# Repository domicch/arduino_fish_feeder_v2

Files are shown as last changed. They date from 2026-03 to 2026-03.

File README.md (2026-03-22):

# Arduino Fish Feeder v2

An automatic fish feeder designed for small, precise dosages. Built around an Arduino Nano with a stepper motor driving a 14-well rotating dispenser and a servo motor to tap food through.

## Photos

<p float="left">
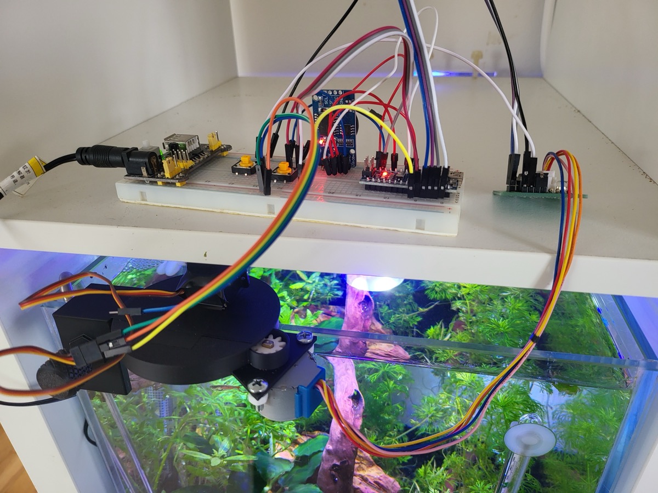
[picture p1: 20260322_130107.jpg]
  
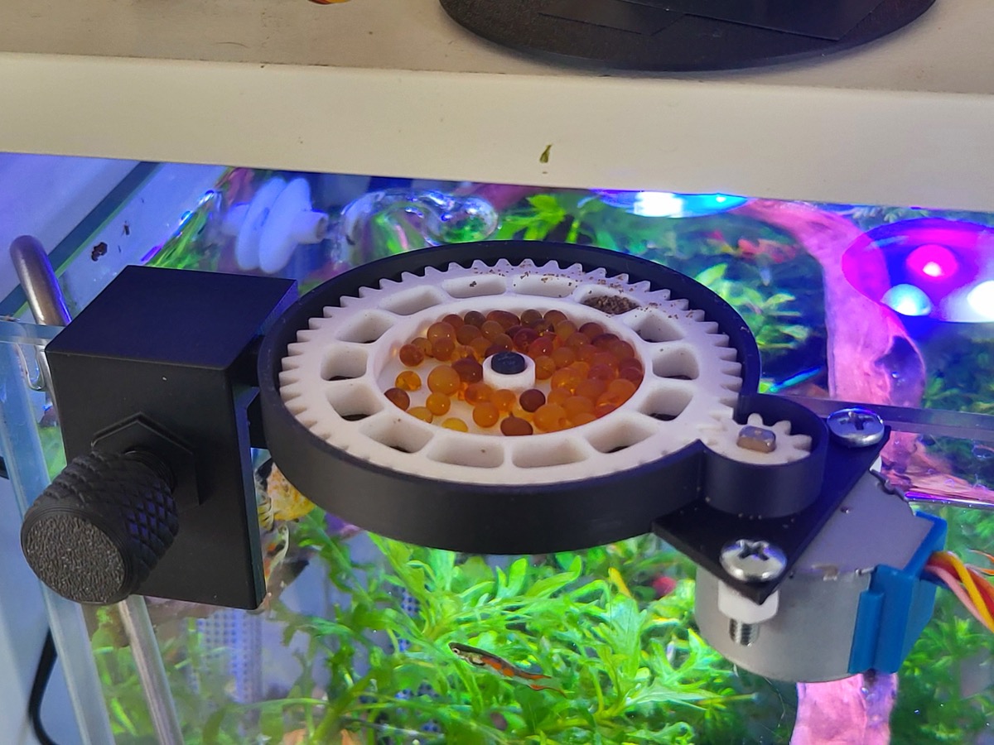
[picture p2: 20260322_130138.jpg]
  
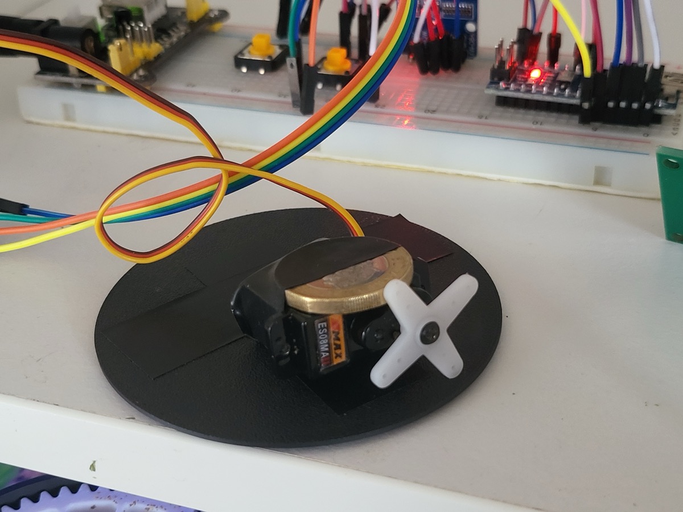
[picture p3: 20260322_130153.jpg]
  
</p>

## 3D Model

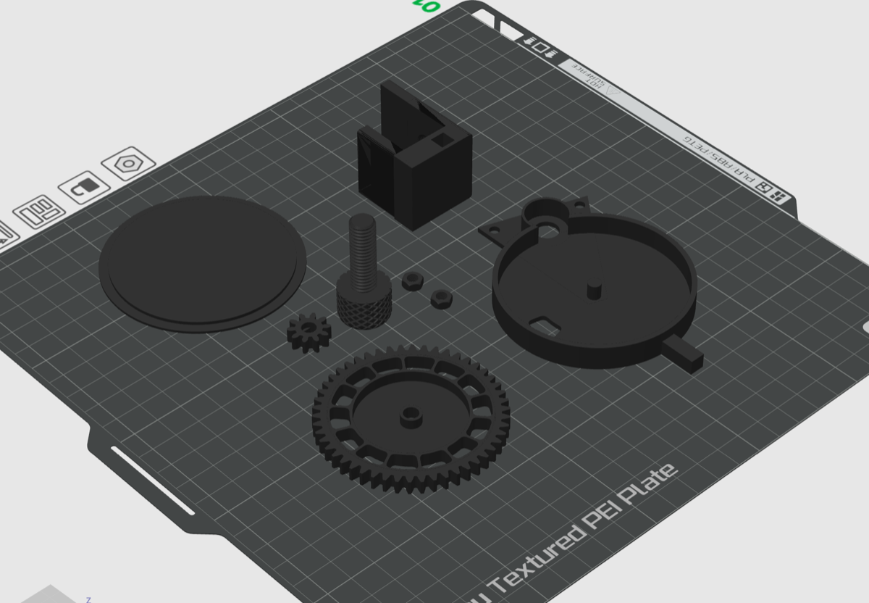
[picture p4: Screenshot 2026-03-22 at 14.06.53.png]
3mf screenshot


The enclosure and dispenser wheel are designed in Bambu Lab's 3MF format. The model file is `models.3mf`.

## Purpose

Most commercial fish feeders dispense food in large, imprecise quantities and only support basic daily scheduling. This feeder is designed for:

- **Precise, small dosages** — a 14-well rotating dispenser controls exactly how much food is released per feeding
- **Flexible scheduling** — feedings can be configured to specific dates and times, not just a daily interval

## Hardware

| Component | Purpose |
|---|---|
| Arduino Nano | Microcontroller |
| 28BYJ-48 stepper motor + ULN2003 driver board | Rotates the food dispenser wheel |
| Servo motor | Taps the dispenser to ensure food drops through |
| DS3231 RTC module (AT24C32 IIC) | Keeps accurate time for scheduling |
| 12V DC transformer + 12V to 5V converter board | Powers the system |
| 3D printed parts | Enclosure, gear system, and dispenser wheel |

### Wiring

| Pin | Connection |
|-----|---|
| D6 | Servo signal |
| D7 | Test button (active low, internal pull-up) |
| D8–D11 | ULN2003 stepper driver |
| A4 | RTC SDA |
| A5 | RTC SCL |

## Technical Challenges Solved

### Low stepper motor torque
The 28BYJ-48 produces very little torque on its own. A **gear reduction system** (3D printed) multiplies the torque enough to reliably rotate the food dispenser.

### Food sticking in wells
Food particles can stick inside the wells and fail to fall through. A **servo motor taps the dispenser** for 60 seconds after each rotation, shaking food loose.

### Precise portioning
The dispenser wheel has **14 wells**. Each feeding advances the wheel by exactly 1/14th of a revolution (730 steps of the stepper motor), releasing one pre-measured portion. The wheel also includes a dedicated space for a **moisture desiccant** to keep the food dry and prevent clumping.

## Software

### Libraries required

- `Stepper.h` (Arduino built-in)
- `Servo.h` (Arduino built-in)
- `RTClib` by Adafruit

### How to compile and flash

1. Install [Arduino IDE](https://www.arduino.cc/en/software)
2. Install the **RTClib** library via the Arduino Library Manager (`Sketch > Include Library > Manage Libraries`, search for `RTClib` by Adafruit)
3. Open `arduino_fish_feeder_v2.ino` in Arduino IDE
4. Select **Arduino Nano** as the board and the correct COM/serial port
5. Click **Upload**

### Configuring the schedule

Feeding times are hard-coded in the `schedules` array near the top of the `Scheduler` class:

```cpp
int schedules[20][6] = { // [year, month, day, hour, minute, second]
    {2026, 3, 22, 0, 10, 0},
    // add more entries here
};
```

Up to 20 entries are supported. The firmware automatically selects the next upcoming scheduled time.

### Setting the RTC clock

With the device connected via USB, open the Arduino IDE Serial Monitor (9600 baud) and send:

- `u` — enter interactive prompts to set the current date and time
- `t` — print the current time read from the RTC

### Manual test feeding

Press the button on **D7** to trigger an immediate feeding cycle (debounced to 500 ms).

## Future Improvements

- More flexible scheduling (recurring daily/weekly rules rather than specific timestamps)
- Wireless control — adjust schedule and trigger feeding remotely over Wi-Fi or Bluetooth

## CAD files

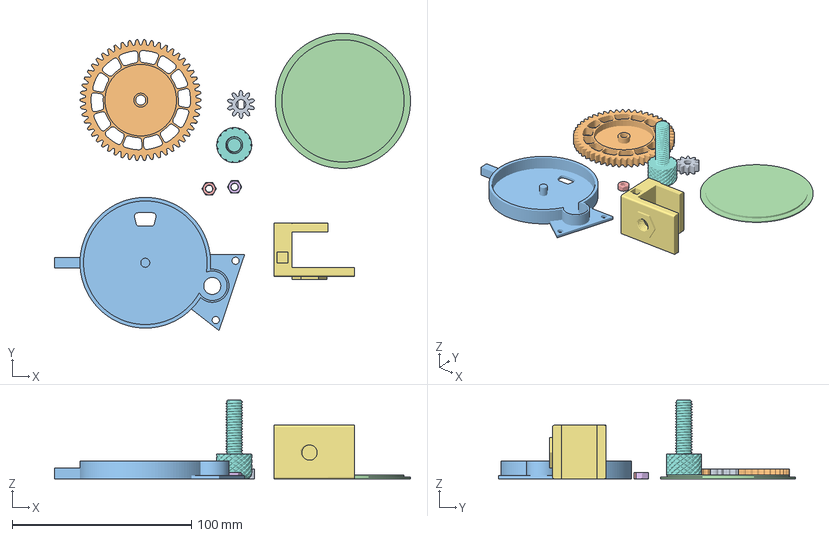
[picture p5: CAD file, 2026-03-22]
models.3mf
198.8 x 166.1 x 44.0 mm
small-gear.stl
big-gear.stl
container.stl
lid.stl
M4 Nut.stl.stl x 2
mount.stl
滚花螺丝.stl

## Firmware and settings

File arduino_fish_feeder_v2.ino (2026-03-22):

#include <Stepper.h>

#include <RTClib.h>
#include <Servo.h>


/**
 * Connections:
 *
 * D6 - servo control pin
 * D7 - test button
 * A4 - CLK SDA
 * A5 - CLK SCL
*/

class Scheduler {
    private:
        RTC_DS3231 rtc;

        int schedules[20][6] = { // [year, month, day, hour, minute, second]
            {2026, 3, 22, 0, 10, 0},            
        };

        bool isAlarmSet = false;
        DateTime nextAlarm;
        void setAlarm();
        String printDateTime(DateTime datetime);
        String printTime(DateTime datetime);

    public:
        void init();
        void setTime();
        String printNow();
        String printAlarm();
        bool checkAlarm();
        void clearAlarm();
        DateTime now();
};

void Scheduler::init() {
    rtc.begin();
    rtc.disable32K();
}

void Scheduler::setTime() {
    // ask user to enter new date and time
    const char txt[6][15] = { "year [4-digit]", "month [1~12]", "day [1~31]",
                            "hours [0~23]", "minutes [0~59]", "seconds [0~59]"};
    String str = "";
    long newDate[6];

    while (Serial.available()) {
    Serial.read();  // clear serial buffer
    }

    for (int i = 0; i < 6; i++) {

      Serial.print("Enter ");
      Serial.print(txt[i]);
      Serial.print(": ");

      while (!Serial.available()) {
          ; // wait for user input
      }

      str = Serial.readString();  // read user input
      newDate[i] = str.toInt();   // convert user input to number and save to array

      Serial.println(newDate[i]); // show user input
    }

    // update RTC
    rtc.adjust(DateTime(newDate[0], newDate[1], newDate[2], newDate[3], newDate[4], newDate[5]));
    Serial.println("RTC Updated!");
}

String Scheduler::printDateTime(DateTime datetime)
{
    char value[30];

    int ss = datetime.second();
    int mm = datetime.minute();
    int hh = datetime.hour();
    int DD = datetime.dayOfTheWeek();
    int dd = datetime.day();
    int MM = datetime.month();
    int yyyy = datetime.year();

    sprintf(value, "%02d-%02d-%04d %02d:%02d:%02d",
            dd, MM, yyyy, hh, mm, ss);
    
    return String(value);
}

String Scheduler::printTime(DateTime datetime)
{
    char value[6];

    int year = datetime.year();
    int month = datetime.month();
    int day = datetime.day();
    int mm = datetime.minute();
    int hh = datetime.hour();

    sprintf(value, "%02d/%02d/%02d %02d:%02d",
            year, month, day, hh, mm);
    
    return String(value);
}

void Scheduler::setAlarm() {
    DateTime now = rtc.now();
    int closestFutureIndex = -1;

    if(sizeof(schedules) == 0) {
        return;
    }

    int rows = sizeof(schedules) / sizeof(schedules[0]);

    // find the closest future timestamp
    for(int i = 0; i < rows; i++) {
        DateTime s (schedules[i][0], schedules[i][1], schedules[i][2], schedules[i][3], schedules[i][4], schedules[i][5]);
        if(s > now && (closestFutureIndex == -1 || s < DateTime(schedules[closestFutureIndex][0], schedules[closestFutureIndex][1], schedules[closestFutureIndex][2], schedules[closestFutureIndex][3], schedules[closestFutureIndex][4], schedules[closestFutureIndex][5]))) {
            closestFutureIndex = i;
        }
    }

    if(closestFutureIndex == -1) {
        Serial.println("no future timestamps found");
        isAlarmSet = false;
        return;
    }

    nextAlarm = DateTime(schedules[closestFutureIndex][0], schedules[closestFutureIndex][1], schedules[closestFutureIndex][2], schedules[closestFutureIndex][3], schedules[closestFutureIndex][4], schedules[closestFutureIndex][5]);
    Serial.print("Alarm set: ");
    Serial.println(printDateTime(nextAlarm));
    isAlarmSet = true;
}

bool Scheduler::checkAlarm() {
    if(!isAlarmSet) {
        setAlarm();
    }

    if(!isAlarmSet) {
        return false;
    }

    return rtc.now() >= nextAlarm;
}

String Scheduler::printNow() {
    return printTime(rtc.now());
}

void Scheduler::clearAlarm() {
    isAlarmSet = false;
    Serial.println("alarm cleared");
}

String Scheduler::printAlarm() {
    if(isAlarmSet) {
        return printTime(nextAlarm);
    }else {
        return "N/A";
    }
}

DateTime Scheduler::now() {
    return rtc.now();
}

const int PIN_TEST_BUTTON = 7;
const unsigned long TEST_BUTTON_DEBOUNCE_MILLISEC = 500UL;
const int stepsPerRevolution = 2048;   //From your motor data sheet, number of steps per revolution
const unsigned long ALARM_POLL_MILLISEC = 1000UL;
const unsigned long MAIN_LOOP_MILLISEC = 200UL;

unsigned long testButtonLastClickTs = 0UL;
unsigned long alarmPollLastTs = 0UL;
int delayCount = 1;    //A counter to keep track of which delay is in use, 1 or 2


Stepper myStepper(stepsPerRevolution, 8, 9, 10, 11);   //Initialize the stepper library on pins 8 through to 11
Servo servo;
Scheduler rtc;

void setup() {
  // put your setup code here, to run once:
  Serial.begin(9600);

  servo.attach(6);

  // test button
  pinMode(PIN_TEST_BUTTON,INPUT_PULLUP);

  Serial.println("Hello");
  rtc.init();

  myStepper.setSpeed(5);
}

// set time
void loop2() {
  // updateLCD();
  String dateTime = rtc.printNow();
  // lcd.setCursor(0, 0);
  // lcd.print(dateTime);

  if (Serial.available()) {
    char input = Serial.read();
    if (input == 'u') rtc.setTime();  // update RTC time
    if(input == 't') Serial.println(rtc.printNow());
  }
}

void loop()
{
    unsigned long mainLoopStartTs = millis();

    if (digitalRead(PIN_TEST_BUTTON) == LOW) {
        if(millis() - testButtonLastClickTs > TEST_BUTTON_DEBOUNCE_MILLISEC) {
            Serial.println("button pressed");
            feed();
            testButtonLastClickTs = millis();
        }
    }

    // scheduler
    if(millis() - alarmPollLastTs > ALARM_POLL_MILLISEC) {
        if(rtc.checkAlarm()) {
            feed();
            rtc.clearAlarm();
        }
        alarmPollLastTs = millis();
    }

    unsigned long now = millis();
    if(now < mainLoopStartTs + MAIN_LOOP_MILLISEC) {
        delay(mainLoopStartTs + MAIN_LOOP_MILLISEC - now);
    }
}

void feed() {
    nextWell();
    tap();
}

void nextWell() {
    //146 steps is 1/14th of a full rotation. Since we have 14 wells, this will index the feeder one space.
    myStepper.step(730);           

    //Turn the motor off when not in use to preserve energy and prevent it from heating up
    digitalWrite(8, LOW);          
    digitalWrite(9, LOW);
    digitalWrite(10, LOW);
    digitalWrite(11, LOW);
}

void tap() {
    servo.write(120); //move
    delay(60000);
    servo.write(90); //stop
}
